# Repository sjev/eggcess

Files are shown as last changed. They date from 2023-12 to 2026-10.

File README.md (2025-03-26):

# Eggcess - chicken coop door for nerds

This is a fun, useful and educative project that combines mechanical design,
3D printing, electronics, IOT technologies and embedded programming.

This is not "just another" chicken coop door opener. In fact, this is a second generation
that I've built, with the main goal to improve *reliability* ... and a good reason to play with Micropython / Circuitpython and learn something new.

**Features**

* sensorless operation - no risk of sensor malfunction
* safe torque - no risk of breaking something if software malfunctions
* stand-alone operation - can go without wifi connection for a long time
* calculation of sunrise and sunset times
* auto-recovery - automatic recalibration if power was lost during movement
* MQTT interface - connect to anything
* logging saved to non-volatile memory
* compact electronics, can be built without soldering, just use jumper wires.

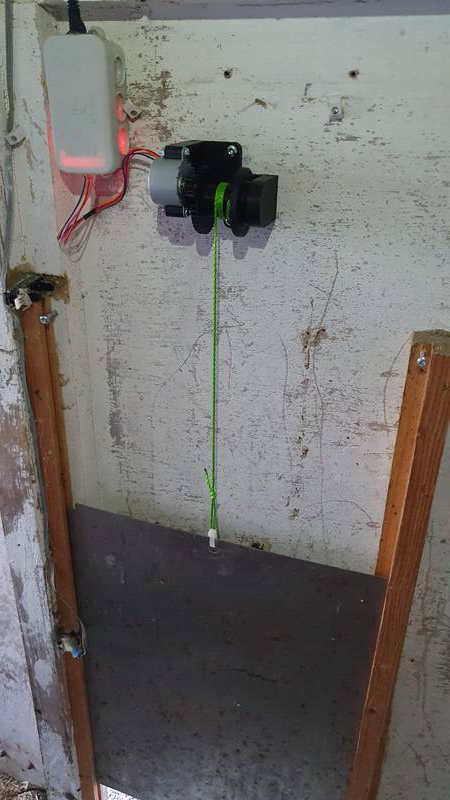
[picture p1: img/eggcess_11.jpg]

*new version*

------------------------------------------

## Quick start

**prepare pc**

* install dev requirements `pip install -r requirements_dev.txt`

**prepare board**

0. connect board via usb.
1. install circuitpython on the board
2. create `settings.toml` based on `config/settings.toml.example`. Copy it to board with `ampy put settings.toml`.
3. hard reset board.

The board should now have wifi connection

* check that the board has wifi connection. connecting with `mpremote` should provide REPL and set terminal header to board ip.
* remove `code.py` from the board
* Upload source files and lookup table:
  - serial: `invoke upload-src`
  - OR copy them manually through web interface.
* install required bundles with `circup  --host <ip> --password <pass> install -r cp_requirements.txt `

## Development
1. Start up VSCode devcontainer. The `Dockerfile` contains all the development goodies, like  stubs.
   - use pytest for running basic tests.
2. use `mpremote run src/<file>.py` *on host system*  to run tests on hardware ( some modules like `door.py` include functional tests when the module is run as `__main__`.
3. (optional) generate lookup table for open and close times using `calculations/calculate_lut.ipynb` if you need a more complex open-close schedule, for example different opening times during weekend, DST adjustments etc.

## Uploading files

* use `invoke` to sync files with the device over serial

      pull         Pull files from the device to the local 'dest' directory, ignoring hidden files and .syncignore patterns.
      push         Push files from the local 'src' directory to the device, ignoring hidden files and .syncignore patterns.
      upload-lut   Upload the 'sun_lut.csv' file using the CircuitPython web workflow API

* use `ampy put ...` to upload individual files over serial
* use [web workflow](https://docs.circuitpython.org/en/latest/docs/workflows.html) to manage device remotely

-------------------------------------------------------

## Homeassistant integration

Install `mqtt` integration.

modify `mqtt` section in `configuration.yaml`:

```yaml
mqtt:
  switch:
      - unique_id: eggcess
        name: "eggcess"
        state_topic: "/eggcess/state"
        command_topic: "/eggcess/cmd"
        payload_on: "open"
        payload_off: "close"
        state_on: "open"
        state_off: "closed"
        retain: false

```

## Mechanics

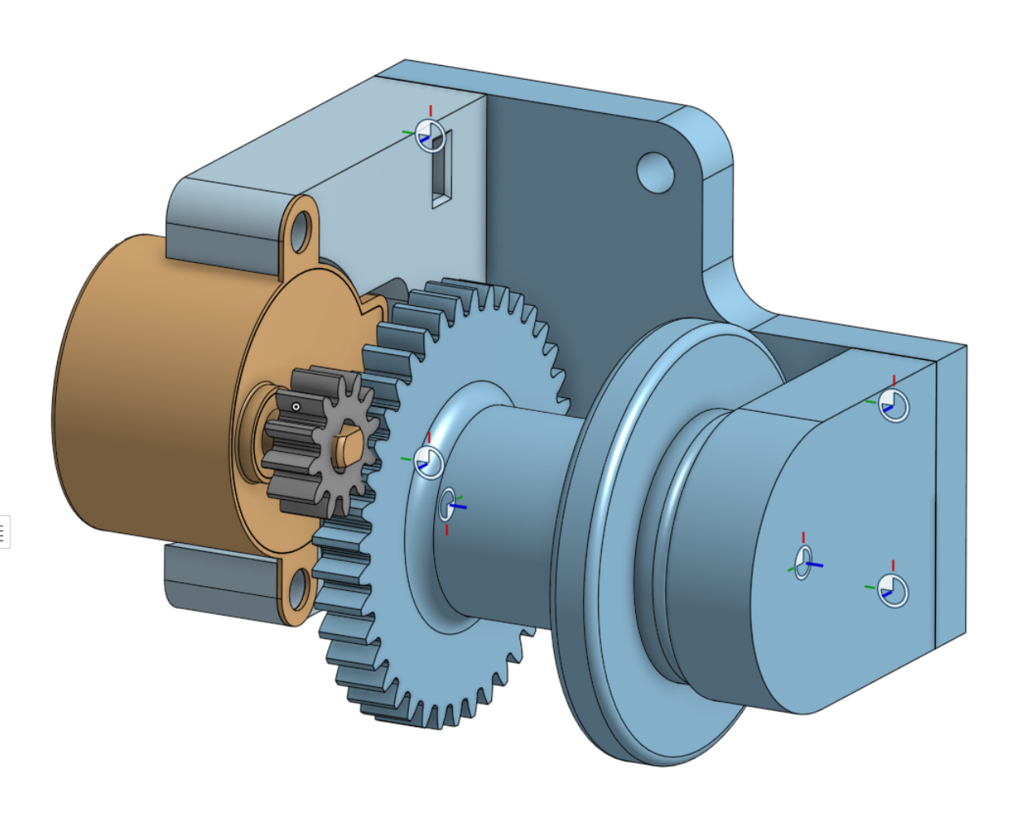
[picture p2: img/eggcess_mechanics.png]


Mechanical design is available on

* [onshape](https://cad.onshape.com/documents/9d1e9d13503836a93d923c99/w/cf41e9abcfc58e38551d4ef1/e/91ab2b97868868ebff4768e5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)
* `stl` folder contains ready-to-print files.

## Electronics

XIAO-ESP32-C3 pinout



soldering connections: [D0..D3] (In Micropython noted as gpio 2..5)

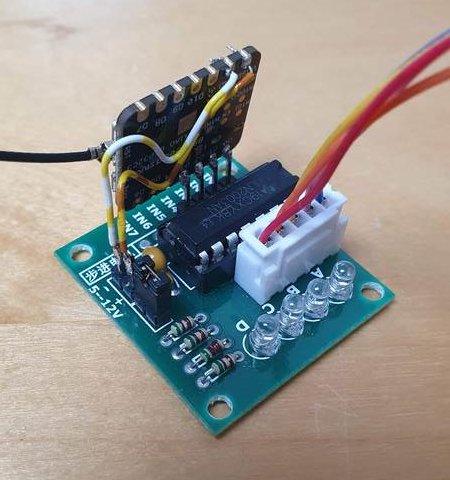
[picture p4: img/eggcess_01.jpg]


---------------------------------------------------------

## Bill of materials

* [Seed Studio XIAO - ESP32-C3](https://www.tinytronics.nl/shop/nl/development-boards/microcontroller-boards/met-wi-fi/seeed-studio-xiao-esp32-c3) - 7 €
* 2x 608ZZ ball bearing - 2x 1 €
* [BYJ48 stepper + ULN2003 driver](https://www.tinytronics.nl/shop/nl/mechanica-en-actuatoren/motoren/stappenmotoren/stappen-motor-met-uln2003-motoraansturing) - 4 €

Total of just 13 euro!

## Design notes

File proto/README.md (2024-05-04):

# Prototype code

Started when starting switch to circuitpython.  Various protos to pre-test compatibility.

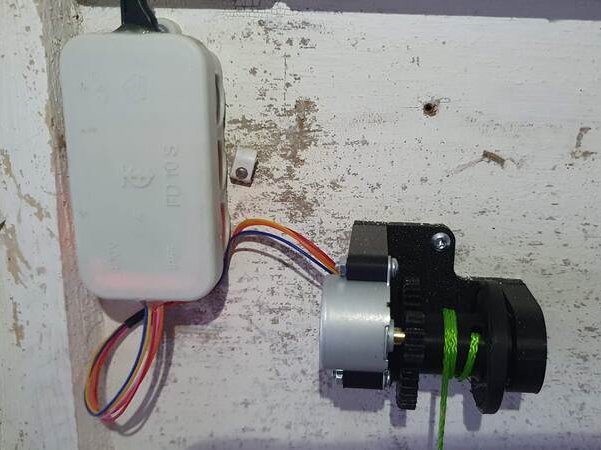
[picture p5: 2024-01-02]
img/eggcess_13.jpg

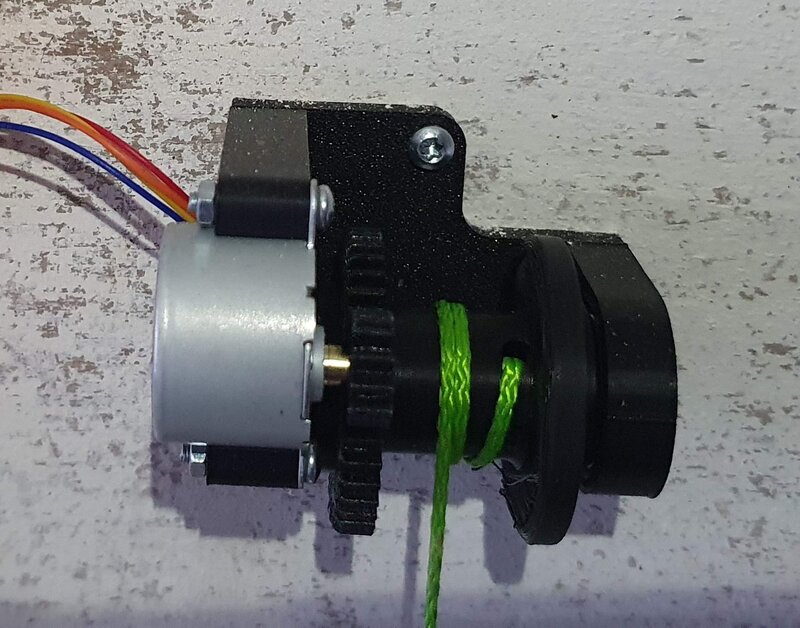
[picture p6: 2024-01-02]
img/eggcess_15.jpg

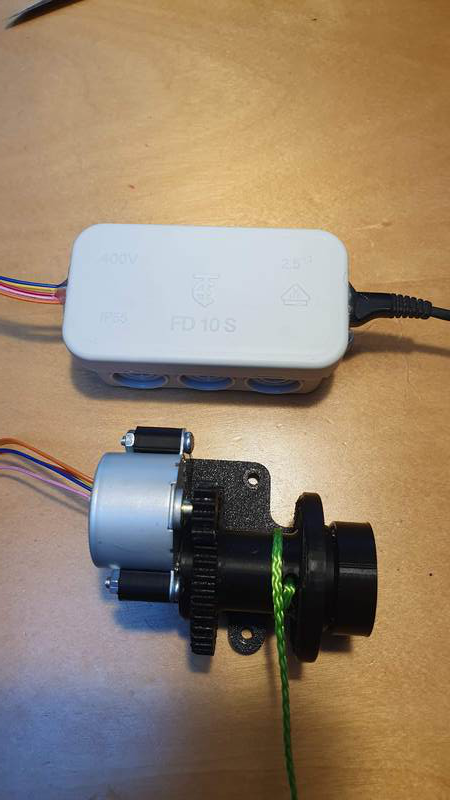
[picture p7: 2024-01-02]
img/eggcess_07.jpg

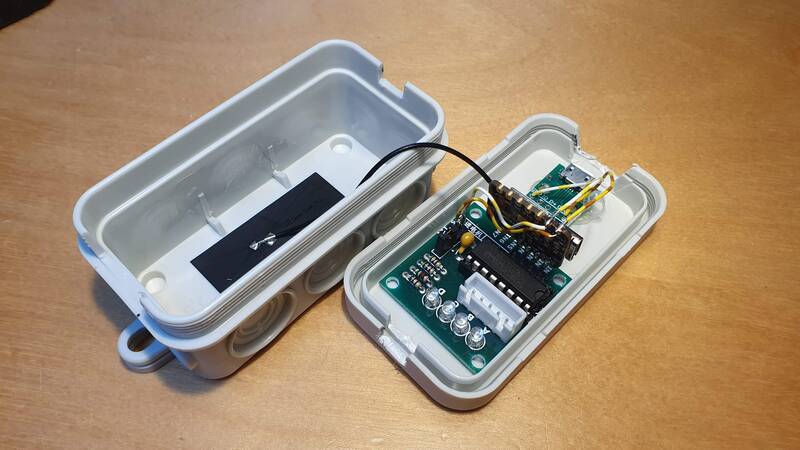
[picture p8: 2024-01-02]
img/eggcess_05.jpg

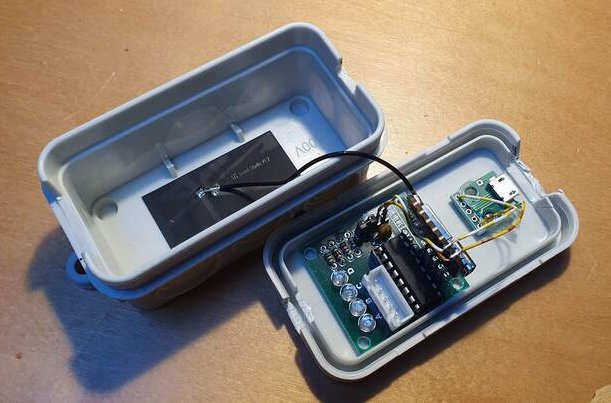
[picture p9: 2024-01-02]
img/eggcess_03.jpg

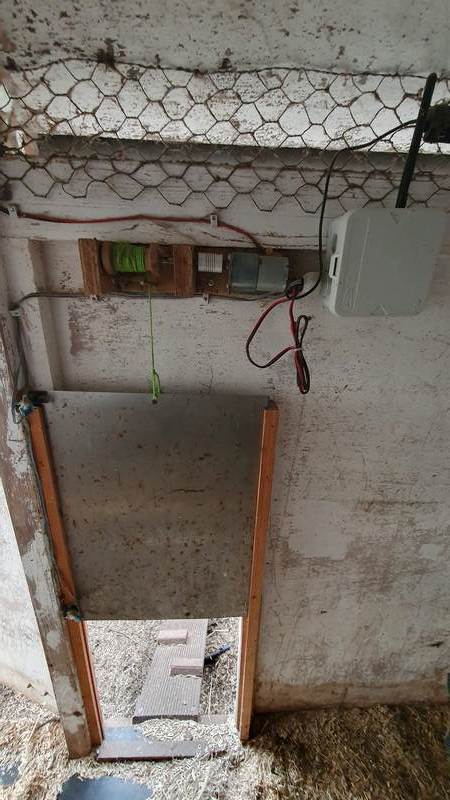
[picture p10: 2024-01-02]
img/eggcess_09.jpg

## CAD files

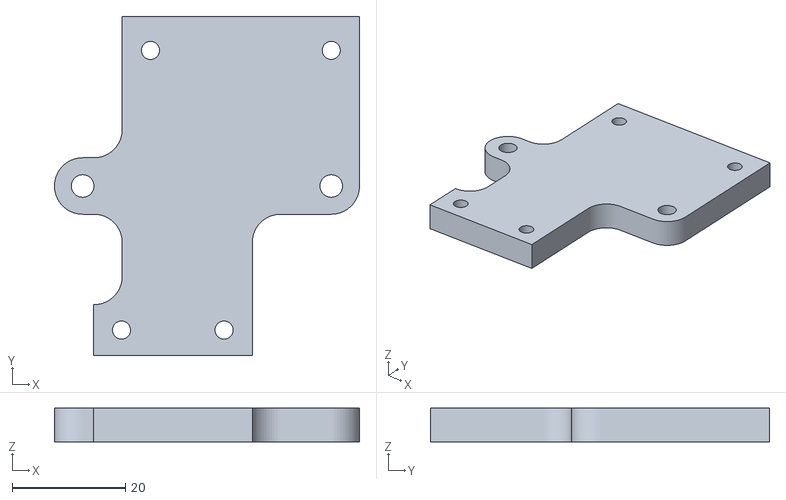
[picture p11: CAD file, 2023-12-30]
stl/bottom plate.stl
54.0 x 60.0 x 6.00

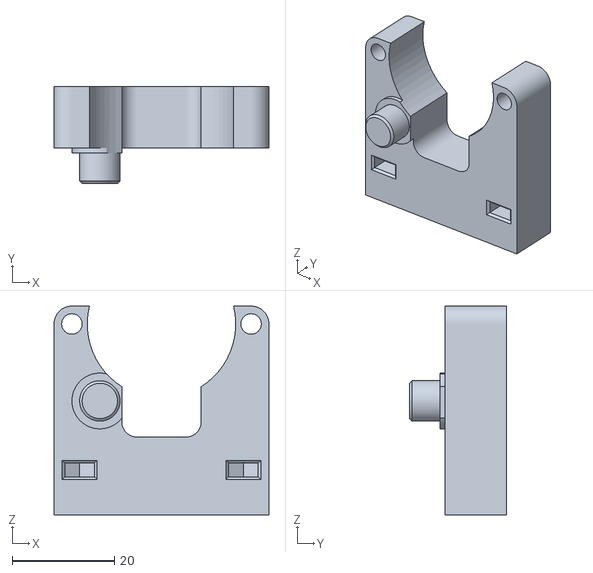
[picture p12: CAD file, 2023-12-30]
stl/motor_bracket.stl
42.0 x 19.0 x 40.8

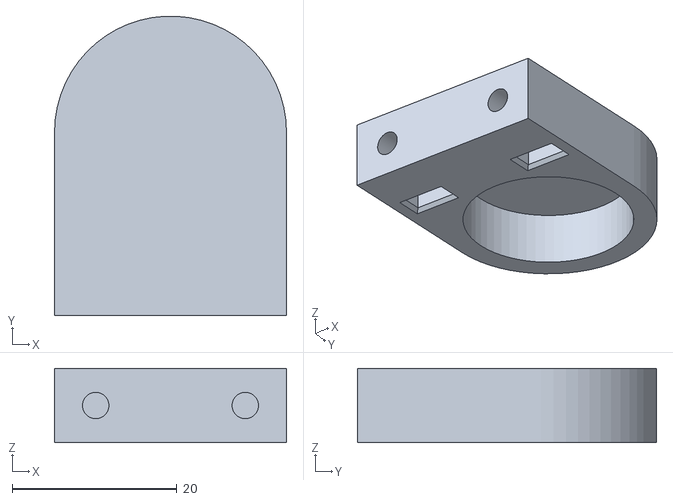
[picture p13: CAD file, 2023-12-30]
stl/bearing_bracket.stl
28.1 x 36.3 x 9.00

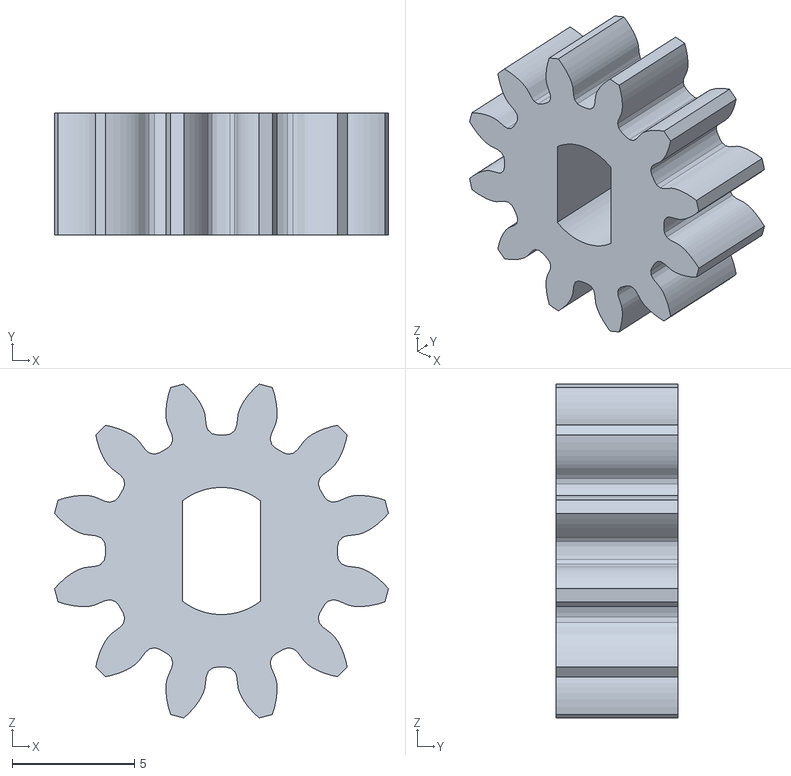
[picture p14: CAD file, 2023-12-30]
stl/motor_gear.stl
13.7 x 5.00 x 13.7

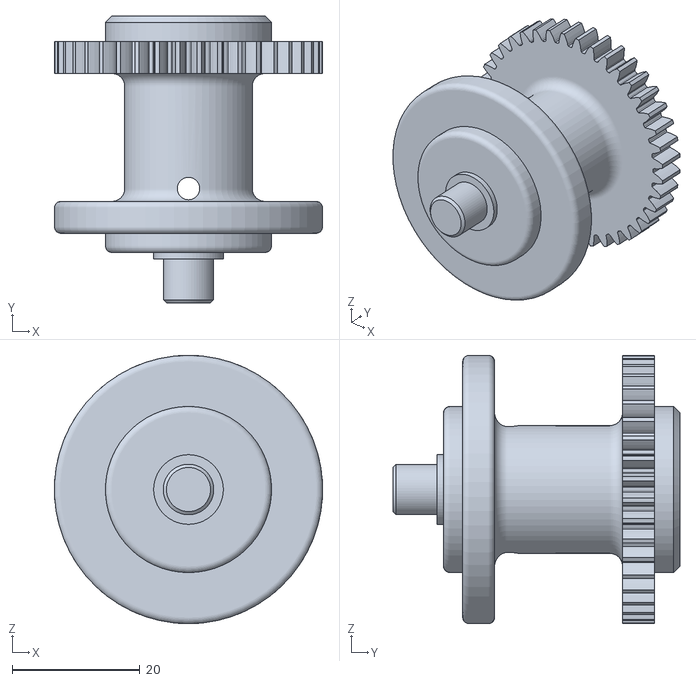
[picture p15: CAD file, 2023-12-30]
stl/pulley.stl
41.9 x 44.9 x 42.0

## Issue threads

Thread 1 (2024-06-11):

Motor wire protector interferes with bracket

baccula, 2024-06-11:
Using generic 28BYJ-48 stepper purchased from Amazon, I am unable to correctly seat the motor in the bracket. The (blue on my motor) plastic wiring cover interferes with the bracket recess on both sides. See attached picture for reference.

I would be happy to adjust the model if you are willing to share the CAD?
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

sjev, 2024-06-12:
Thanks for mentioning this. I had the same issue, so I just filed of the interfering parts of the motor, took less time than to adust the model ;-).

You are very welcome to change the model, it is found on onshape:
https://cad.onshape.com/documents/9d1e9d13503836a93d923c99/w/cf41e9abcfc58e38551d4ef1/e/91ab2b97868868ebff4768e5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

Not sure how forking/merging for cad models work, lets find out!

baccula, 2024-06-12:
Thank you for the Onshape link. I don't have much familiarity with Onshape, so I think I will follow your lead and file the motor cover down. Thanks for sharing your design and code too, great work!

Closed 2024-06-12.

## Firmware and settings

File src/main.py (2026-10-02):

"""

main module for coop_door

"""

import gc
import json
import os
import time

import microcontroller
from microcontroller import watchdog as wdt
from watchdog import WatchDogMode, WatchDogTimeout
import wifi

import logger
import mqtt
import timing
from daily_tasks import (
    CloseDoorTask,
    OpenDoorTask,
    SetClockTask,
    TruncateLogTask,
    UpdateDoorTimesTask,
    init_open_close,
)
from door import Door

__version__ = "3.6.0"


DEVICE_NAME = os.getenv("CIRCUITPY_WEB_INSTANCE_NAME", "eggcess")
STATUS_TOPIC = os.getenv("STATUS_TOPIC", f"/{DEVICE_NAME}/status")
STATE_TOPIC = os.getenv("STATE_TOPIC", f"/{DEVICE_NAME}/state")

BOOT_RETRY_S = 60  # wait before reset when the clock cannot be set at boot

def set_clock_at_boot() -> None:
    """Keep the RTC if NTP fails. Without a valid RTC there is no schedule: retry via reset."""
    try:
        timing.update_ntp_time()
    except timing.MaxRetriesExceeded:
        logger.error("NTP failed at boot")

    if not timing.is_rtc_set():
        logger.debug(f"RTC not set, resetting in {BOOT_RETRY_S} s")
        time.sleep(BOOT_RETRY_S)
        microcontroller.reset()


set_clock_at_boot()


T_START = time.time()

# show topics
logger.debug(f"{DEVICE_NAME=}")
logger.debug(f"{STATUS_TOPIC=}")
logger.debug(f"{STATE_TOPIC=}")

logger.info(f"*** system start  v{__version__}***")

# set watchdog
if wdt is None:
    raise RuntimeError("Watchdog not available")

try:
    wdt.timeout = 300.0  # 5 minutes
    wdt.mode = WatchDogMode.RESET
    wdt.feed()
except Exception as e:
    logger.error(f"Could not init watchdog: {e}")


door = Door()
led = door.stepper.pins[0]


# create tasks
open_task = OpenDoorTask(exec_time=None, door=door)
close_task = CloseDoorTask(exec_time=None, door=door)
set_clock_task = SetClockTask(exec_time=1.0)
set_door_timing_task = UpdateDoorTimesTask(0.1, open_task, close_task)
truncate_log_task = TruncateLogTask(0.2)

all_tasks = [
    open_task,
    close_task,
    set_clock_task,
    set_door_timing_task,
    truncate_log_task,
]


def command_callback(client, topic, command):  # pylint: disable=unused-argument
    print(f"Received command: {command}")

    if command == "open":
        logger.info("opening by command")
        door.open()
    elif command == "close":
        logger.info("closing by command")
        door.close()
    elif command == "reset":
        logger.info("resetting by command")
        microcontroller.reset()
    else:
        logger.error(f"invalid command {command}")


def flash_led():
    led.value = 1
    time.sleep(0.01)
    led.value = 0


def status_msg() -> str:
    """generate status string"""

    # Pre-initialize the message dictionary with static values
    msg = {
        "name": DEVICE_NAME,
        "door_state": door.state,  # assuming door.state is static, remove if it changes
    }

    network = wifi.radio.ap_info

    # Update dynamic values
    utc_time = time.localtime()
    uptime = time.time() - T_START

    msg.update(
        {
            "ip": str(wifi.radio.ipv4_address),
            "uptime_h": round(uptime / 3600, 3),  # type: ignore
            "mem_free": gc.mem_free(),  # type: ignore
            "rssi": network.rssi,  # type: ignore
            "date": timing.date(),
            "time": f"{utc_time[3]:02}:{utc_time[4]:02}:{utc_time[5]:02}",
            "open": (
                timing.hours2str(open_task.exec_time) if open_task.exec_time else "None"
            ),
            "close": (
                timing.hours2str(close_task.exec_time)
                if close_task.exec_time
                else "None"
            ),
            "door_state": door.state,  # update door state in case it changes
        }
    )
    status = json.dumps(msg)
    logger.debug(f"status: {status}")
    return status


def main():
    """main function"""

    try:
        set_door_timing_task.execute()
        logger.info(f"Door state: {door.state}")
        init_open_close(open_task, close_task)

        mqtt_link = mqtt.Connection(mqtt.get_client(on_message=command_callback))

        while True:
            flash_led()
            mqtt_link.service(STATUS_TOPIC, status_msg)
            wdt.feed()
            for task in all_tasks:
                task.execute()

    except WatchDogTimeout:
        logger.error("Watchdog timeout")
        microcontroller.reset()

    except Exception as e:
        logger.error(f"Main crashed: {type(e).__name__}: {e}")

    logger.info("Main loop ended, resetting in 10 seconds")
    time.sleep(10)
    microcontroller.reset()


if __name__ == "__main__":
    main()

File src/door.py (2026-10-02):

"""Manage the door for CircuitPython."""

import os
import board
import json

from timing import time_str
from uln2003 import Stepper, FULL_ROTATION
import logger

STATE_FILE = "door_state.json"

DRIVE_PINS = [board.D0, board.D1, board.D2, board.D3]  # type: ignore

MM_PER_REV = 19.6  # mm travel per revolution of the motor
TRAVEL_MM = int(os.getenv("TRAVEL_MM", "330"))  # door travel distance in mm
OPEN_EXTRA_MM = 10  # extra mm to open door, push against mechanical stop

logger.debug(f"Door travel distance: {TRAVEL_MM} mm")

# Door states
STATE_OPEN = "open"
STATE_CLOSED = "closed"
STATE_MOVING = "moving"
STATE_UNKNOWN = "unknown"

# Door directions
DIRECTION_OPEN = -1
DIRECTION_CLOSE = 1


class State:
    """Represents the door state."""

    def __init__(self, name: str = STATE_UNKNOWN):
        self.name = name

    def __str__(self):
        return self.name

    def __repr__(self):
        return self.name

    @classmethod
    def load(cls) -> "State":
        """Load state from file."""
        try:
            with open(STATE_FILE, "r") as f:
                data = json.load(f)
                logger.debug(f"Loaded state: {data}")
                return cls(data.get("state", STATE_UNKNOWN))
        except (OSError, ValueError):
            # ValueError: file corrupted by a power loss during write
            logger.debug("Failed to load state, returning unknown state")
            return cls(STATE_UNKNOWN)

    def save(self):
        """Save state to file."""
        logger.debug(f"Saving state: {self.name}")
        data = {"state": self.name, "time": time_str()}
        with open(STATE_FILE, "w") as f:
            json.dump(data, f)


class Door:
    """Door interface for open/close actions."""

    def __init__(self, auto_reset: bool = True):
        self.stepper = Stepper(DRIVE_PINS)
        self._state = State.load()
        logger.debug(f"Initial door state: {self._state}")

        if self.state in {STATE_UNKNOWN, STATE_MOVING} and auto_reset:
            logger.debug("Resetting door")
            self.open()

    @property
    def state(self) -> str:
        """Return the current door state."""
        return self._state.name

    @state.setter
    def state(self, new_state: str):
        """Set a new door state and save it if needed."""
        self._state = State(new_state)
        self._state.save()

    def move(self, direction: int, distance_mm: float):
        """Move the door in the specified direction with feedback after each revolution."""
        revolutions = distance_mm / MM_PER_REV
        logger.debug(
            f"Moving: distance_mm={distance_mm}, direction={direction}, revolutions={revolutions:.2f}"
        )

        full_revs = int(revolutions)
        for i in range(full_revs):
            self.stepper.step(FULL_ROTATION, direction)
            logger.debug(f"Completed revolution {i + 1}")

        remainder = revolutions - full_revs
        if remainder > 0:
            steps = int(remainder * FULL_ROTATION)
            self.stepper.step(steps, direction)
            logger.debug(f"Completed remainder: {remainder:.2f}")

    def open(self, distance_mm: float = TRAVEL_MM + OPEN_EXTRA_MM):
        """Open the door."""
        logger.debug("Attempting to open door")
        if self.state == STATE_OPEN:
            logger.debug("Door is already open")
            return

        logger.info("Opening door")
        self.state = STATE_MOVING
        self.move(DIRECTION_OPEN, distance_mm)
        self.state = STATE_OPEN
        logger.info("Door is open")

    def close(self, distance_mm: float = TRAVEL_MM):
        """Close the door."""
        logger.debug("Attempting to close door")
        if self.state == STATE_CLOSED:
            logger.debug("Door is already closed")
            return

        logger.info("Closing door")
        self.state = STATE_MOVING
        self.move(DIRECTION_CLOSE, distance_mm)
        self.state = STATE_CLOSED
        logger.info("Door is closed")


def test():
    """Test the door functionality."""

    logger.debug("********* Running door test *********")
    door = Door(auto_reset=False)
    door.state = STATE_UNKNOWN
    test_distance = 10

    door.open(test_distance)
    door.close(test_distance)


if __name__ == "__main__":
    test()

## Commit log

2023-12-30 switch to mm interface
2023-12-30 add stl
    [bearing_bracket.stl, bottom plate.stl, motor_bracket.stl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]
2024-01-01 fix date formatting bug
    [timing.py]
2024-01-01 Addwatchdog timer
2024-01-18 close 35 mins after sunset
    [sun_lut.csv]
2024-05-03 fix async issues, add gc
    [main.py]
2024-05-04 update circuitpython
2024-05-04 switch container to circuitpython
2024-05-05 changed timing to circuitpython
2024-05-05 port motor driver
2024-05-05 remove full_step as it does not work
    [uln2003.py]
2024-05-06 add lut
    [sun_lut.csv]
2024-05-06 fix led
2025-03-22 switch to python
2025-03-23 auto reset on next day
    [daily_tasks.py]
2025-03-23 switch to string for latlon
2025-03-23 add error handling for watchdog initialization
    [main.py]
2025-03-24 refactor mqtt error handling
    [main.py]
2025-03-24 use watchdog reset. update to 3.3.3
    [main.py]
2025-03-24 update times without reboot
    [daily_tasks.py, main.py]
2025-03-24 add pin connections
2025-03-24 try to reconnect on mqtt errors
    [main.py]
2025-03-24 move flash led to separate function
2026-10-02 fix(timing): retry ntp before giving up
    The return inside the retry loop ended the function after the first
    attempt, so a failed NTP request was never retried or reported.
    [timing.py]
2026-10-02 feat(tasks): not_before in local time with eu dst
    Removes the need for an external MQTT open command to get a fixed
    local opening time across DST changes.
    [daily_tasks.py, timing.py]
2026-10-02 fix: keep door running without wifi, mqtt or log storage
    [door.py, logger.py, main.py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]
2026-10-02 fix(main): drop reload_on_error safety net
    A Ctrl-C counts as an error, so the board reloaded instead of opening
    the REPL, and the web console then ignored Ctrl-C until a hard reset.
    main() already resets on any exception.
    [main.py]
2026-10-02 test: run hardware tests over wifi with invoke hw-test
    Stages src/ in /test on the device, runs hw_tests/run.py through the
    web serial console and always restarts production code.
